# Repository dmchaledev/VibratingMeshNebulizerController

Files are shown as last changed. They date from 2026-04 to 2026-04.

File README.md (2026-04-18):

# Nimbus Nebulizer Controller

> **WARNING: THIS IS NOT AN FDA-APPROVED MEDICAL DEVICE.**
> This project is a research workaround for educational and investigational purposes only.
> It has not been evaluated, cleared, or approved by the FDA or any regulatory body.
> It is not intended to diagnose, treat, cure, or prevent any disease. Building and using
> this circuit is done entirely at your own risk. See [DISCLAIMER.md](DISCLAIMER.md) for
> full safety and legal information.

An open-source controller for vibrating mesh nebulizers, built on a breadboard for under $75. Based on [Microchip AN2265](https://static5.arrow.com/pdfs/2016/10/27/10/14/17/387/mcp_/manual/82300002265a.pdf) vibrating mesh nebulizer reference design.

## Why This Exists

The Aerogen Solo is a medical-grade vibrating mesh nebulizer used in ICUs and home ventilator circuits. The controller that drives it — the Aerogen Pro-X — costs **$2,700 out of pocket** and is not always covered by insurance. The nebulizer cup itself is ~$40 and has two simple electrical contacts: the leads of a piezoelectric ring. All the controller does is generate the right AC signal to make it vibrate.

This project provides everything you need to build a working controller on a breadboard using off-the-shelf parts from DigiKey, a $3 microcontroller, and free development tools from Microchip.

### v3.1 — Rechargeable + Display

v3.1 adds the three quality-of-life features that matter most for an
every-day nursery device: a rechargeable LiPo cell, USB-C charging,
and a status display.

- **Rechargeable 1S LiPo pouch cell** — ~2000 mAh (103450). Drops into
  an internal bay in the enclosure. Runs ~3-5 treatments per charge.
- **USB-C charging via TP4056 + DW01A** — plug in any USB-C cable to
  recharge. DW01A handles over-charge, over-discharge and short-circuit
  protection. The firmware adds a software cutoff at 3.1 V so it warns
  and stops cleanly before the hardware cutoff trips.
- **16x2 character OLED on the lid** — shows state, resonant
  frequency, elapsed treatment time, battery percent and voltage.
  Default is a character OLED (Winstar / Newhaven / Matrix Orbital,
  ~$25) which stays readable at any LiPo voltage (3.0–4.2 V). A
  cheap HD44780 LCD (~$3) also works; set `LCD_IS_OLED = 0`.
- **Split enclosure** — base and lid are now separate SCAD files
  sharing an `enclosure_config.scad`, so you can iterate on either
  without re-rendering the other.
- **Zero-parts battery monitor** — the PIC's built-in Fixed Voltage
  Reference doubles as a VDD meter, so battery voltage is read via
  ADC without any external divider.

### v3.0 — Turnkey Build

- **Single build path** — order a pre-assembled PCB from JLCPCB, plug in a boost module, flash firmware, done.
- **Continuous treatment mode** — runs until you press stop or the cup is empty.
- **Dry-cup auto-stop** — detects when the cup is empty and shuts down safely.
- **Frequency caching** — saves the resonant frequency to flash memory for fast startup.
- **Smart re-sweep** — when resonance drifts during a long session, does a fast 150ms targeted re-sweep.
- **3D-printable connector and enclosure** — parametric OpenSCAD designs.

## How It Works

The Aerogen Solo cup contains a PZT (Lead Zirconate Titanate) piezoelectric ring bonded to a perforated stainless steel mesh. When driven at its resonant frequency (~90-150 kHz) with ~30-60 Vpp, the mesh vibrates and pushes liquid through thousands of laser-drilled holes, creating a fine aerosol (MMAD ~3.4 um).

The controller:
1. **Boosts** battery/USB voltage up to ~10-20V
2. **Generates** a high-voltage AC waveform at 30-60 Vpp
3. **Sweeps** frequency from ~90-150 kHz to find the PZT's resonant peak
4. **Locks** onto that frequency and runs until medication is nebulized

## Vibrating Mesh Nebulizer Compatibility

This controller drives a PZT piezoelectric ring at its resonant frequency — the same fundamental mechanism used by all vibrating mesh nebulizers. The frequency sweep approach means it is **not hard-coded to a single device** and can, in principle, find the resonant frequency of any PZT-based mesh nebulizer cup.

| Brand | Product Line | Likely Compatible | Notes |
|---|---|:---:|---|
| **Aerogen** | Solo, Solo with Pro-X | Yes | Primary target of this project. ~128 kHz typical resonance. |
| **OMRON** | MicroAir (U22, U100) | Likely | Uses PZT mesh, similar frequency range. Different cup form factor — will need custom contact adapter. |
| **PARI Pharma** | eFlow / eFlow Rapid | Likely | PZT mesh design. Resonant frequency may differ — the sweep range in `config.h` may need widening. |
| **Philips Respironics** | InnoSpire Go | Possible | Vibrating mesh type. Limited public data on drive parameters. Test with caution. |
| **Drive DeVilbiss** | Aerogen-based devices | Yes | Several DeVilbiss ventilator-integrated nebulizers use Aerogen Solo cups internally. |

**Key caveats:**
- Each manufacturer's cup has a different mechanical form factor — you'll need to figure out how to make electrical contact with the two PZT leads for non-Aerogen cups
- Resonant frequencies vary by manufacturer and even unit-to-unit. The firmware sweeps 90-150 kHz by default; adjust `SWEEP_FREQ_MIN_HZ` and `SWEEP_FREQ_MAX_HZ` in `config.h` if your cup resonates outside that range
- Drive voltage requirements differ. **Always start with low voltage** and increase gradually
- This project has only been tested against Aerogen Solo cups. Compatibility with other brands is inferred from the shared operating principle, not from direct testing

## Repository Structure

```
├── README.md                 ← You are here
├── DISCLAIMER.md             ← Safety and legal notice (READ THIS FIRST)
├── docs/
│   ├── BUILD_GUIDE.md        ← Turnkey build guide and nursery durability tips
│   ├── DIAGRAMS.md           ← Visual diagrams (state machine, signal flow, etc.)
│   ├── JLCPCB_ORDERING_GUIDE.md ← How to order pre-assembled PCBs from JLCPCB
│   ├── BOM_TURNKEY.csv       ← Bill of materials — JLCPCB assembled build (~$15-25/board)
│   ├── SHOPPING_LIST.md      ← Where to buy every part, organised per supplier
│   └── IMPROVEMENTS.md       ← External review: suggested repo/design improvements
├── firmware/
│   ├── README.md             ← How to compile and flash
│   └── src/
│       ├── main.c            ← Main program and state machine
│       ├── config.h          ← Tunable parameters (frequencies, voltages, modes)
│       ├── peripherals.h     ← Peripheral function declarations
│       ├── peripherals.c     ← PIC16F1713 hardware initialization + HEF flash
│       ├── sweep.h           ← Frequency sweep declarations
│       └── sweep.c           ← Full sweep, narrow sweep, and frequency caching
└── hardware/
    ├── WIRING.md             ← Pin-by-pin wiring reference
    ├── adapters/             ← 3D-printable nebulizer cup connector
    │   ├── README.md         ← Measurement guide and assembly instructions
    │   ├── aerogen_connector_plug.scad ← Connector plug for Aerogen Solo cup pins
    │   └── universal_adapter.scad      ← Parametric adapter for other cup brands
    └── enclosure/            ← 3D-printable controller enclosure (v3.1 split)
        ├── enclosure_config.scad       ← Shared dimensions used by base and lid
        ├── controller_enclosure.scad   ← Base with LiPo + TP4056 bay
        └── controller_enclosure_lid.scad ← Lid with LCD/OLED window + standoffs
```

## Quick Start

1. **Read [DISCLAIMER.md](DISCLAIMER.md)** — understand what you're building
2. **Order the PCB** — follow [docs/JLCPCB_ORDERING_GUIDE.md](docs/JLCPCB_ORDERING_GUIDE.md), JLCPCB assembles the board for you
3. **Order parts** — copy the per-supplier cart from [docs/SHOPPING_LIST.md](docs/SHOPPING_LIST.md) (boost module, LiPo, TP4056, pogo pins, cables, screws). Full authoritative BOM in [docs/BOM_TURNKEY.csv](docs/BOM_TURNKEY.csv).
4. **3D print** the connector plug and enclosure from [hardware/](hardware/)
5. **Compile and flash** firmware per [firmware/README.md](firmware/README.md) (default config is ready to go)
6. **Assemble** — mount PCB in enclosure, plug in boost module and connector cable
7. **First power-up** following the procedure in [docs/BUILD_GUIDE.md](docs/BUILD_GUIDE.md)

## Key Reference Documents

| Resource | Description |
|---|---|
| [AN2265 Application Note (PDF)](https://static5.arrow.com/pdfs/2016/10/27/10/14/17/387/mcp_/manual/82300002265a.pdf) | Microchip's reference design this project is based on |
| [Microchip Demo Page](https://www.microchip.com/en-us/solutions/medical/demonstrations-and-design-files/vibrating-mesh-nebulizer) | Official source code download |
| [PIC16F1713 Datasheet](https://www.microchip.com/en-us/product/pic16f1713) | MCU datasheet |
| [Arrow Reference Design](https://www.arrow.com/en/reference-designs/vibrating-mesh-nebulizer-reference-design/f2a9476a8ee42cf52a40b74023c3b682227100c55cf2) | Arrow's page for the AN2265 design |
| [MDPI: Frequency & Voltage Effects](https://www.mdpi.com/2076-3417/11/3/1296) | Research on mesh nebulizer drive parameters |

## Estimated Cost (v3.1)

| Item | Cost |
|---|---|
| JLCPCB assembled PCB (5-board min) | ~$10-16/board |
| Boost module (MT3608) | ~$1-2 |
| 1S LiPo pouch cell (103450, 2000 mAh) | ~$8-12 |
| TP4056 + DW01A Type-C charger | ~$0.50-2 |
| 16x2 character OLED (Winstar WEH001602A, default) | ~$22-28 |
| 3D-printed connector + enclosure | ~$3-5 |
| Pogo pins + JST cables + screws | ~$3-5 |
| **Per-unit total (LCD)** | **~$30-45** |
| **Per-unit total (character OLED)** | **~$45-70** |
| Programmer (MPLAB Snap, one-time) | ~$35 |
| **First build total** | **~$75-105** |

JLCPCB minimum order is 5 boards, so you get spares. The programmer is a one-time purchase.

**Compare to:** Aerogen Pro-X controller — **$2,700** out of pocket.

## License

MIT — see [LICENSE](LICENSE).

*Based on Microchip AN2265 Rev B and publicly available research.*

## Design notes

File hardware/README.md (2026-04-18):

# Hardware

This directory holds everything needed to build the physical controller:
the wiring map, 3D-printable parts, and pointers to the schematic and
PCB sources.

## Contents

```text
hardware/
├── WIRING.md              ← Pin-by-pin reference for the breadboard build
├── adapters/              ← 3D-printable nebulizer cup connector
│   ├── README.md
│   ├── aerogen_connector_plug.scad
│   └── universal_adapter.scad
├── enclosure/             ← 3D-printable controller enclosure (split for v3.1)
│   ├── enclosure_config.scad     ← Shared dimensions for base + lid
│   ├── controller_enclosure.scad ← Base with LiPo + TP4056 bay
│   └── controller_enclosure_lid.scad
└── openscad/              ← Optional vendored OpenSCAD AppImage (Linux x86_64)
```

## Schematic and PCB Sources

The PCB this project ships against is the **Microchip AN2265 reference
design** with the modifications described in `docs/BUILD_GUIDE.md`. Two
ways to get the design files:

1. **Microchip / Arrow** — original reference design (PDF schematic,
   gerbers, BOM):
   - <https://www.microchip.com/en-us/solutions/medical/demonstrations-and-design-files/vibrating-mesh-nebulizer>
   - <https://www.arrow.com/en/reference-designs/vibrating-mesh-nebulizer-reference-design/f2a9476a8ee42cf52a40b74023c3b682227100c55cf2>
2. **JLCPCB-ready bundle** — see `docs/JLCPCB_ORDERING_GUIDE.md` for the
   pre-modified gerbers and a step-by-step ordering walkthrough.

Native KiCad sources (`.kicad_sch` / `.kicad_pcb`) for the v3.1 board
are **not yet** in this repo. Track <https://github.com/dmchaledev/VibratingMeshNebulizerController/issues>
for the open issue or open one if you'd like to help port the gerbers.

## Working with the OpenSCAD Models

Every printable part is a parametric `.scad` file. Two ways to render:

```bash
# GUI: open the file, F5 preview, F6 render, then File > Export > STL
openscad hardware/enclosure/controller_enclosure.scad

# Command line: produce an STL non-interactively
openscad -o /tmp/enclosure.stl hardware/enclosure/controller_enclosure.scad
```

Shared dimensions for the enclosure base and lid live in
`enclosure/enclosure_config.scad`. Edit those constants to retune both
parts at once instead of duplicating values.

CI renders every `.scad` in this directory on push (see
`.github/workflows/openscad.yml`). Files matching `*_config.scad` /
`*_common.scad` are treated as include-only and rendered indirectly by
their consumers — don't put a top-level `module` call in those files.

## About `openscad/OpenSCAD-2021.01-x86_64.AppImage`

A copy of the Linux OpenSCAD AppImage is vendored here for offline
builders. It is large (~40 MB) and not required if you've installed
OpenSCAD from your distribution's package manager or from
<https://openscad.org/downloads.html>.

> **Note:** vendoring binaries in Git inflates clone size for everyone.
> A future cleanup will move this into a release artifact instead. If
> you don't need the offline copy, install OpenSCAD via your package
> manager and ignore this directory.

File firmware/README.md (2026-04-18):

# Firmware — Build and Flash Instructions

## Prerequisites

### Software (all free)

1. **MPLAB X IDE** — download from https://www.microchip.com/en-us/tools-resources/develop/mplab-x-ide
2. **XC8 Compiler** — download from https://www.microchip.com/en-us/tools-resources/develop/mplab-xc-compilers
   - Install in Free mode (no license needed)
   - The free mode generates slightly less optimized code but works perfectly fine

### Hardware

- **MPLAB Snap** (~$35, DigiKey PG164100-ND) or **PICkit 4** (~$60) or **PICkit 5** (~$90)
- 5-wire connection from programmer to PIC16F1713 ICSP pins (see [hardware/WIRING.md](../hardware/WIRING.md))

## Quick Start (Make)

The repo ships with a Makefile that wraps the XC8 invocation:

```bash
cd firmware
make            # → firmware/build/nebulizer.hex
make program    # → flashes via MPLAB Snap (set PROGRAMMER=pickit4 etc.)
make clean
```

The Makefile auto-discovers every `.c` file in `src/`, so new sources
(such as `lcd.c` added in v3.1) are picked up without edits.

## Quick Start (Command Line)

If you'd rather call the compiler directly:

```bash
# Navigate to the firmware source directory
cd firmware/src

# Compile (adjust the XC8 path if needed). Pass every .c source.
xc8-cc -mcpu=16F1713 -O1 -o nebulizer.hex \
    main.c peripherals.c sweep.c lcd.c

# Program the chip (with MPLAB Snap connected via USB)
# Use MPLAB IPE (Integrated Programming Environment) or:
mdb.sh -e "device PIC16F1713; hwtool snap; program nebulizer.hex; quit"
```

## Using MPLAB X IDE

### Create a New Project

1. Open MPLAB X IDE
2. File > New Project
3. Select: Microchip Embedded > Standalone Project
4. Device: **PIC16F1713**
5. Tool: select your connected programmer (Snap, PICkit 4, etc.)
6. Compiler: **XC8 (latest version)**
7. Project name: `NebulizerController`
8. Finish

### Add Source Files

1. In the project tree, right-click "Source Files" > Add Existing Item
2. Add all `.c` files from this `src/` directory:
   - `main.c`
   - `peripherals.c`
   - `sweep.c`
   - `lcd.c`
3. Right-click "Header Files" > Add Existing Item
4. Add all `.h` files:
   - `config.h`
   - `peripherals.h`
   - `sweep.h`
   - `lcd.h`

### Compile

1. Click the **Build** button (hammer icon) or press F11
2. The output window should show `BUILD SUCCESSFUL`
3. If you get errors, verify:
   - XC8 compiler is selected (Project Properties > Compiler)
   - Device is set to PIC16F1713

### Program the Chip

1. Connect the programmer to the PIC16F1713 via the ICSP header
2. Connect the programmer to your computer via USB
3. Click **Make and Program Device** (green arrow with chip icon)
4. The output window should show programming succeeded

### Verify

After programming:
- The red LED should blink once at power-up (indicating the MCU is running)
- Press the button — the controller should begin sweeping (green LED will blink during sweep, then go solid when locked on resonance)

## Alternative: Download Microchip's Original AN2265 Source

If you'd rather use the original reference code:

1. Visit https://www.microchip.com/en-us/solutions/medical/demonstrations-and-design-files/vibrating-mesh-nebulizer
2. Download the source code ZIP
3. Open the included MPLAB X project directly
4. This is the exact code from the application note — it will compile for the SOIC package but works identically on the DIP version

## Source File Overview

| File | Purpose |
|---|---|
| `config.h` | All tunable parameters — frequencies, voltages, timing, firmware version. **Edit this first.** |
| `peripherals.h/c` | PIC16F1713 hardware initialization (oscillator, NCO, DAC, ADC, CWG, GPIO, UART) |
| `sweep.h/c` | Frequency sweep algorithm — scans for PZT resonance |
| `lcd.h/c` | Bit-bang I2C driver for the 16x2 character LCD/OLED on the lid |
| `main.c` | State machine: idle → sweep → run → stop. Button handling, treatment timer, LED control |

## Adjusting Parameters

All user-adjustable parameters are in `config.h`. The most important ones:

| Parameter | What It Does | Default |
|---|---|---|
| `SWEEP_FREQ_MIN_HZ` | Lower frequency bound | 90,000 Hz |
| `SWEEP_FREQ_MAX_HZ` | Upper frequency bound | 150,000 Hz |
| `SWEEP_STEP_HZ` | Frequency resolution | 500 Hz |
| `BOOST_TARGET_DAC` | Drive voltage level (**start low!**) | 16 |
| `TREATMENT_TIME_SEC` | Auto-shutoff timer | 600 (10 min) |

After changing `config.h`, rebuild and reprogram the chip.

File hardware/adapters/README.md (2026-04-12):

# Nebulizer Cup Connector System

3D-printable connector plug and adapters that provide reliable electrical contact between the controller and nebulizer cups.

**Read [DISCLAIMER.md](../../DISCLAIMER.md) before building.**

---

## Overview

The Aerogen Solo cup has a small rectangular connector housing (~1/2" x 1/2") on its bottom face containing two protruding pins (the PZT leads). The connector plug mates with this housing and connects via a flexible cable to the controller enclosure.

1. **A connector plug** that inserts into the cup's pin housing and makes spring-loaded contact
2. **A flexible cable** (30-50cm stranded wire) connecting the plug to the controller
3. **A JST-XH connector** for clean, repeatable connection at the controller end

---

## Available Designs

| File | Cup Model | Status |
|---|---|---|
| `aerogen_connector_plug.scad` | Aerogen Solo / Solo with Pro-X | Ready (approximate dimensions — update with calipers) |
| `universal_adapter.scad` | OMRON MicroAir, PARI eFlow, others | Parametric template (needs measurements) |

Both files are **parametric OpenSCAD** designs. Measure your cup, enter the dimensions, and export STL for printing.

---

## What You Need

### Hardware (per connector)

| Qty | Item | Source | Cost |
|-----|---|---|---|
| 2 | P75-B1 pogo pin sockets (receptacles) | Amazon/AliExpress "P75-B1 pogo pin" | ~$3/50-pack |
| 1 | JST-XH 2-pin connector + header pair | Amazon/DigiKey | ~$0.50 |
| 1 | Flexible stranded wire, 30-50cm (24-28 AWG, 2 conductors) | Any | ~$0 |
| 1 | 3D printed connector plug | Your printer or JLCPCB 3D printing | ~$1-3 |
| 1 | Small zip tie (for strain relief) | Any | ~$0 |

### Tools

- 3D printer (PETG or SLA resin) or order from JLCPCB/Shapeways
- Soldering iron (to solder wires to pogo pin sockets)
- Calipers (to verify cup connector dimensions)
- JST crimp tool or solder

---

## Measurement Guide — Aerogen Solo

The connector housing on the bottom of the Aerogen Solo cup looks like this:

```
    BOTTOM VIEW (looking up at the cup base)
    ==========================================

         +------------------+
         |                  |
         |    o        o    |   <-- two protruding pins
         |  (pin 1)  (pin 2)|
         |                  |
         +------------------+
              ~1/2" wide

    SIDE VIEW (cross-section through connector)
    ==========================================

         Cup body
        +---------+
        |         |
        | housing |       ^
        |  +---+  |       | housing_height
        |  | o |  |       |  (pin recess depth)
        |  +---+  |       v
        +----+----+
             |  pin protrusion
             v
```

### Critical Measurements (use calipers)

| Parameter | What to Measure | Estimated Value |
|---|---|---|
| `housing_width` | Width of the rectangular connector housing | ~12.7mm (1/2") |
| `housing_depth` | Depth of the rectangular connector housing | ~12.7mm (1/2") |
| `pin_spacing` | Center-to-center distance between the two pins | ~3.175mm (1/8") |
| `pin_diameter` | Diameter of each pin | ~1.0mm |
| `pin_length` | How far pins protrude from the housing floor | ~4.0mm |
| `housing_height` | Depth of the housing recess | ~6.0mm |

**The most critical measurement is `pin_spacing`.** If this is off by more than 0.2mm, the pogo sockets won't align with the pins. Measure this first and most carefully.

---

## Assembly

### Step 1: Print the Connector Plug

1. Open `aerogen_connector_plug.scad` in [OpenSCAD](https://openscad.org/) (free)
2. Update measurements with your caliper readings
3. Press F5 to preview, F6 to render
4. Export STL: File > Export > Export as STL
5. Print settings:
   - **Material:** SLA resin (best precision) or PETG
   - **Layer height:** 0.12-0.2mm (finer = better socket channel fit)
   - **Infill:** 50%+
   - **Supports:** Yes, for socket channels

### Step 2: Install Pogo Sockets

1. Insert a P75-B1 pogo socket (receptacle end up) into each channel from the bottom of the plug
2. The open bore of each socket should face the insertion face (toward the cup pins)
3. Optionally apply a tiny drop of CA glue to secure the socket barrel — avoid getting glue on the spring mechanism
4. Solder a 24-28 AWG stranded wire to each socket's solder cup

### Step 3: Route Cable

1. Route both wires through the cable channel to the cable exit
2. Thread the cable through the controller enclosure's cable gland **before** terminating
3. Crimp or solder wires to a JST-XH 2-pin plug
4. Secure cable with a zip tie in the strain relief slot

**Cable tips:**
- Use flexible silicone-insulated wire (survives repeated flexing)
- Keep cable 30-50cm (shorter = less noise pickup at 100+ kHz)
- Twist the two wires together to reduce EMI
- **No polarity requirement** — the PZT is an AC device

### Step 4: Test

1. Press the connector plug onto the Aerogen Solo cup's pins
2. You should feel slight resistance as the pins engage the pogo sockets
3. Measure continuity: < 1 ohm from each JST pin to the corresponding cup pin
4. Tug gently on the cable — the strain relief should hold

---

## Troubleshooting

| Problem | Cause | Fix |
|---|---|-----|
| Plug won't fit in housing | Plug too wide / deep | Increase `plug_clearance` by 0.1mm, reprint |
| Plug too loose in housing | Too much clearance | Decrease `plug_clearance` by 0.1mm |
| Pins don't align with sockets | `pin_spacing` measurement off | Re-measure with calipers, update, reprint |
| No continuity through socket | Solder joint broke or socket not seated | Re-solder wire, re-seat socket |
| Intermittent contact | Socket spring worn or medication residue | Clean with isopropyl alcohol, replace socket |
| Cable breaks at plug | Repeated flexing without strain relief | Secure cable with zip tie, use stranded wire |

---

## Design Notes

### Why Pogo Sockets (not clips or bare wire)?

The Aerogen Solo cup has a 28-day life, meaning regular cup changes. The connector plug needs to handle hundreds of connect/disconnect cycles reliably. Pogo pin sockets provide:

- **Self-centering** — spring mechanism guides the cup pin into alignment
- **Consistent contact force** — ~75g per pin regardless of insertion depth
- **100,000+ cycle rating** — effectively infinite for this application
- **Low contact resistance** — gold-plated tips, < 50 milliohm

### Why a Plug (not a Cradle)?

The previous adapter design used a cradle that the cup sat in. The plug design is better because:

- **Matches the actual connector** — the cup has pins in a housing, so we make a plug for that housing
- **Smaller and lighter** — just a small block on the end of a cable
- **More flexible positioning** — the cable lets you position the cup anywhere relative to the controller
- **Easier to print** — no large cradle to support during printing

### Cable Length

Keep the cable between 30-50cm. At the operating frequency of 100+ kHz:
- Longer cables act as antennas, picking up noise
- Cable capacitance can affect the output waveform
- The LC output circuit is tuned for a specific load — long cables add parasitic inductance

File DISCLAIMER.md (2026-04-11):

# Disclaimer and Safety Notice

## Read This Before You Build Anything

This project documents the construction of an electronic controller for a vibrating mesh nebulizer based on publicly available reference designs and datasheets. It is provided for **educational and informational purposes**.

## This Is Not a Medical Device

- This is **not** an FDA-cleared or CE-marked medical device
- It has **not** been tested or validated by any regulatory body
- It has **not** undergone electromagnetic compatibility (EMC) testing
- It has **not** been evaluated for electrical safety (IEC 60601)

## If You Build This

You are accepting personal responsibility for:

- **Verifying** the circuit operates correctly before connecting to a nebulizer cup
- **Testing** with normal saline first, never medication, until operation is stable and repeatable
- **Monitoring** the nebulizer cup temperature during operation — warmth indicates overdriving
- **Current-limiting** your power supply during development to prevent damage
- **Starting with low drive voltages** and increasing gradually — excess voltage can depolarize or crack the piezoelectric element
- **Keeping the circuit isolated** from any ventilator circuit during testing
- **Understanding** the electrical and clinical risks you are accepting

## Aerogen Solo Cup Lifespan

The Aerogen Solo cup has a manufacturer-specified 28-day intermittent-use life. This does not change with a DIY controller. Do not attempt to extend cup life beyond manufacturer specifications.

## Electrical Safety

- The boost converter in this circuit produces voltages up to 20V DC and the output stage generates 30-60 Vpp AC at ultrasonic frequencies
- While these voltages are not typically dangerous to adults, exercise standard electronics safety practices
- Never operate the circuit near water or conductive liquids other than what's in the nebulizer cup
- Keep the prototype away from children when powered

## Why This Exists

This project exists because the healthcare system sometimes fails people. When a child needs a $40 nebulizer cup driven by a simple AC signal, and the only legal way to get the controller costs $2,700 out of pocket, some parents have no choice but to learn the electronics themselves. This repository attempts to make that path as safe and informed as possible.

None of that changes the risks above. Be careful. Test thoroughly. When in doubt, ask for help.

## License

This project is released under the MIT License. The authors and contributors accept no liability for any damages arising from the use of this information. See [LICENSE](LICENSE).

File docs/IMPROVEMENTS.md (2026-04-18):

# Nimbus Nebulizer Controller — Improvement Suggestions

An external engineer's assessment of the repo at v3.1, with concrete
suggestions ordered by "bang for the buck." Written from the
perspective of someone looking at this project for the first time with
fresh eyes.

**Context.** This is a personal-use, educational build for a nursery
device driven 6+ times per day. It's not FDA-approved and is not
intended for distribution. That framing matters — some suggestions
below are worth it only if you want to make the design more accessible
to *other* builders; others are worth it just to make your own build
cheaper and faster.

**Scope.** This memo does not second-guess safety decisions already
made in the firmware. The soft LiPo cutoff, dry-cup auto-stop, and
max-DAC clamp are all clearly right. Suggestions are additive to those.

---

## TL;DR — Top 5 Concrete Wins

Ranked by impact ÷ effort. Each is expanded later in the doc.

| # | Suggestion | Effort | Payoff |
|---|---|---:|---|
| 1 | **Swap the $22–28 character OLED for a $3 SSD1306 0.96" OLED** | ~1 day firmware work | **Saves ~$20–25 per unit.** Single biggest line-item win. Adds graphical capability as a bonus. |
| 2 | **Publish pre-rendered STL + pre-built HEX as GitHub Release artifacts** | ~2 hr of CI glue | Removes the MPLAB X + OpenSCAD install barrier for anyone who doesn't need to modify. First-build wall-clock time drops ~1 hr. |
| 3 | **Evict root clutter: move PNG/PDF to `docs/images/` and `docs/references/`, rename `Nebulizer Reference Design/` (no space), drop the 39 MB vendored OpenSCAD AppImage** | ~1 hr | 40 MB lighter clone. Root directory becomes instantly scannable. Fixes the dir-name-with-space that your own `hardware/README.md` already flagged. |
| 4 | **Add an absolute-max treatment-time safety cap (e.g., 60 min) in CONTINUOUS mode** | ~20 LOC | Defense-in-depth. `CONTINUOUS + dry-cup-miss + silent sweep fail` is currently unbounded. |
| 5 | **Add `docs/GLOSSARY.md` + a single "Which build path is for me?" decision doc at root** | ~2 hr | First-time visitors currently hit PZT, NCO, CWG, HEF, FVR, MMAD, ICSP, HD44780, PCF8574, TP4056, DW01A, WS0010 within 10 pages. A one-pager demystifies all of them. |

Everything below is supporting detail and lower-priority items.

---

## 8. Prioritised Backlog

If I were picking up this repo Monday morning and had a week:

**Day 1 — free wins (no risk):**

- Move root PNGs → `docs/images/`, PDF → `docs/references/`, delete
  the vendored 39 MB OpenSCAD AppImage (publish as release asset
  instead), rename `Nebulizer Reference Design/` → `docs/references/
  an2265_reference/`. (§1.1)
- Add `docs/GLOSSARY.md` and `docs/CHOOSE_YOUR_PATH.md`. (§1.2, §1.3)
- Collapse cost tables into a single `docs/COSTS.md` linked from the
  rest. (§1.4)
- Add top-level `Makefile` with `firmware`, `stl`, `test`, `check`
  targets that delegate to the existing sub-Makefiles. (§1.7)

**Day 2 — release hygiene:**

- GitHub Actions workflow that publishes pre-rendered STLs and a
  default `.hex` on every tag. (§2.3)
- Surface `firmware/tests/` in README. (§1.6)

**Day 3 — safety adds:**

- `TREATMENT_HARD_MAX_SEC` cap (§5.1), `BOOST_VFDBK_MAX_ADC` trip
  (§5.2), resonance plausibility window (§5.3), power-on self-test
  (§5.4). All ~100 LOC of firmware, fully host-testable.

**Day 4–5 — BOM optimisation (requires PCB rev):**

- Swap character OLED for SSD1306 0.96" (§2.1).
- Standardise on JST-XH + M3 (§2.2).
- Panelise the PCB for 10-up on JLCPCB.

**Day 6 — architecture rethink (optional):**

- USB-C PD trigger path in parallel with the MT3608 (§2.5).

**Beyond:** RP2040 port, logging, kit fulfilment — all §7 items are
separate projects in their own right.

## 9. Cross-References

- `docs/SHOPPING_LIST.md` — concrete per-supplier cart list for every
  part in the current v3.1 BOM, organised to minimise shipping trips.
- `docs/BOM_TURNKEY.csv` — authoritative BOM; SHOPPING_LIST is the
  "how to buy it" layer on top.
- `CHANGELOG.md` — history of what was tried and why. Read this
  before proposing anything that sounds like a revert.

---

*This memo was written as an external review and reflects one
reader's judgement. The maintainer's priorities and safety decisions
take precedence.*

### 6.1  Things that are notably well done — don't regress

Worth calling out explicitly so future contributors know what *not* to
"simplify away":

- **Stubbed-transclusion test pattern** in `firmware/tests/`
  (`#define` around hardware blocks, then `#include` the `.c`). Lets
  the host compiler run the same source that ships. Clean solution to
  the "`xc.h` isn't a host header" problem.
- **`LCD_IS_OLED` single driver for three different 1602 modules.**
  One codepath, three displays, $3–$28 price range. Nice.
- **FVR-as-ADC-reference battery meter** — zero external parts for
  battery voltage read. Elegant.
- **HEF frequency caching** with narrow re-sweep fallback —
  measurable UX improvement (150 ms vs 2.4 s cold start).

### 6.2  Config drift between docs and code

`config.h`'s pin comments and `hardware/WIRING.md`'s pin table are
duplicates that can drift. Two options:

- Generate `WIRING.md` from `config.h` with a short Python script in CI
- Or just add a comment at the top of each: "source of truth:
  `config.h`" vs "source of truth: `WIRING.md`", and link reciprocally

I'd go with the second — lighter touch.

### 6.3  Bit-bang I²C vs hardware MSSP

`lcd.c` bit-bangs I²C on RC4/RC5. The PIC16F1713 has an MSSP module
that could run hardware I²C at 100 or 400 kHz with less CPU overhead.
Given that the LCD refresh is only 2 Hz, this is **not** worth
touching — the bit-bang is simpler and works. Flag for future
contributors: don't "optimise" this unless you're freeing CPU for
something else.

### 6.4  UART debug default

`UART_ENABLED = 1` by default is good for debugging; consider flipping
to 0 for tagged releases to save a handful of bytes of flash and
reduce the chance of someone confused by UART traffic they didn't
intend to see. `BUILD_GUIDE.md` already documents enabling it when
needed.

## 7. Bigger Bets — Worth Considering, Not Recommending

Each of these is a larger architectural shift. They're listed for
completeness, not as near-term proposals.

### 7.1  Port firmware to Raspberry Pi Pico (RP2040)

- **Pros.** $4 board with native USB mass-storage bootloader — no
  $35 programmer ever again. Free GCC toolchain. More RAM/flash.
  Easier for hobbyist contributors to get into.
- **Cons.** Complete firmware rewrite. Abandons the AN2265 lineage
  that underpins the project's credibility. PIO makes frequency
  generation straightforward but PIO assembly is a new thing to
  learn. The RP2040 family is younger and has a fresher supply chain
  risk profile.
- **Verdict.** Interesting as a **parallel** target, not a
  replacement. A `firmware-rp2040/` alongside `firmware/` would let
  contributors pick.

### 7.2  Arduino Nano "breadboard try-before-you-buy" target

A stripped-down firmware that runs on an Arduino Nano with a single
MOSFET and a boost module, producing mist on a benchtop without any
PCB fabrication. Aimed at people who want to validate the concept in
an evening before committing to JLCPCB. Fires the NCO via AVR
Timer1/OC1A at ~100 kHz.

- **Pros.** On-ramp for hobbyists.
- **Cons.** Divergent codepath, more maintenance. Probably not worth
  it unless the project wants to broaden its audience.

### 7.3  WiFi-connected variant (ESP32-C3) for treatment logging

Log every treatment (start time, resonance frequency found, elapsed
duration, battery at start, dry-cup trigger vs manual stop) to a
local MQTT broker or a file on SD. For a chronic-care nursery use
case, that's a real clinical-value add.

- **Pros.** Observability. Lets a parent or care team notice "cup is
  getting less efficient" before the mesh fully fails.
- **Cons.** Wildly out of scope for v3.1. Security becomes a concern.
  Probably a v5 discussion.

### 7.4  Sell pre-assembled kits

Nothing about this project would be hard to fulfill at ~$60/unit as
a kit including a flashed PCB, printed parts, and all cables. There's
demand — Aerogen Pro-X at $2,700 has priced out most home users. But
taking money for a medical-adjacent device opens FDA/CE/liability
questions that aren't worth touching as an individual maintainer.
Note it exists, don't pursue it.

 — Concrete Per-Unit Savings

Starting from v3.1's ~$60 midpoint BOM with character OLED:

| Change | Before | After | Saving |
|---|---:|---:|---:|
| SSD1306 OLED (§2.1) | $25 | $3 | **−$22** |
| All-JST-XH + all-M3 kits (§2.2) | $8 | $3 | **−$5** |
| Panelize 5 boards → 10 in one JLCPCB order | $14/board | $11/board | **−$3/board** |
| USB-C PD trigger in place of MT3608 (§2.5) | $2 | $2 | $0 direct, but removes the mis-calibration failure mode |
| Drop the vendored AppImage | — | — | No $ saving, but 40 MB clone saving |
| **Net per-unit savings if you do §2.1 + §2.2 + panelize** | | | **~$30 / unit** |

Put differently: the **same budget** that bought 5 v3.1 units now
buys 10.

## 4. Speed-to-Build — Friction Inventory

Actual wall-clock time for a first-time builder, broken down:

| Step | Today | With the proposals |
|---|---:|---:|
| MPLAB X + XC8 install | ~45 min | 0 (use pre-built `.hex`, §2.3) |
| OpenSCAD install + render | ~20 min | 0 (use pre-rendered STL, §2.3) |
| MT3608 trim-pot calibration | ~10 min + a multimeter | 0 (USB-C PD trigger, §2.5) |
| JLCPCB lead time | 4–10 business days | unchanged |
| 3D print base + lid + plug | 3 × separate queues | 1 plate print (§2.7) |
| PIC flash via Snap | ~2 min | unchanged |
| Enclosure assembly | ~30 min | unchanged |

**Before:** roughly 2 hours active work + 1 week lead time for a
first build, assuming nothing goes wrong.

**After §2.3 alone:** 1 hour active work + 1 week lead time. The
"download MPLAB" yak is gone for casual builders.

## 5. Safety-Robustness Additions

These are additive to existing safety features, not replacements.

### 5.1  Absolute-max treatment-time cap regardless of mode

`TREATMENT_MODE_CONTINUOUS` runs until button-press, dry-cup
detection, or battery cutoff. That's correct **when those detections
fire.** In the (low-probability) case where the cup is wet but low-
fill and the dry-cup detection is marginal, the treatment could run
indefinitely.

Add an absolute ceiling:

```c
/* firmware/src/config.h — new */
#define TREATMENT_HARD_MAX_SEC   3600   /* 60 min absolute cap, any mode */
```

In `main.c`, the treatment-time tick comparison already exists in
TIMED mode — just also run it in CONTINUOUS with `TREATMENT_HARD_MAX_SEC`.
Fewer than 20 LOC and meaningful defense-in-depth.

### 5.2  VBOOST overvoltage trip (MODULE mode)

If the MT3608 trim-pot drifts or is bumped, the boost output can
swing up to ~28 V. The PZT can be damaged or depolarised at those
levels. You already read VBOOST via `ADC_CH_BOOST_VFDBK` for the
"Vboost too low" diagnostic — also trip on "Vboost too high."

```c
/* in sweep.c / main.c VBOOST check path */
if (boost_v_adc > BOOST_VFDBK_MAX_ADC) {
    lcd_show_error("VBOOST HIGH", "Check trim pot");
    state = STATE_ERROR;
    /* Don't start sweep; PZT protection */
}
```

Pick `BOOST_VFDBK_MAX_ADC` at ~15 V scaled through R5/R8 — leaves
margin above nominal 12 V but trips cleanly below any level
concerning for the PZT.

### 5.3  Resonance-implausibility guard

The firmware currently accepts any peak above `RESONANCE_THRESHOLD`
anywhere in the sweep range. If EMI or ADC noise produces a false
peak at, say, 91 kHz for an Aerogen Solo cup (which resonates ~128
kHz), the controller happily "locks" and drives the PZT off-resonance,
heating the mesh without producing mist.

Add a plausibility window: reject peaks that fall outside
`[PLAUSIBLE_MIN_HZ, PLAUSIBLE_MAX_HZ]` (per-brand) or outside ±10 kHz
of the cached frequency if one exists. Prompts a full re-sweep
instead of a bad lock.

### 5.4  Power-on self-test

On boot, before the first button press:

1. Measure VDD (you already do this)
2. Measure VBOOST (already supports this)
3. Drive NCO at a low-duty known frequency for 10 ms with no cup and
   confirm current-sense stays below an idle threshold

If any check fails, splash screen shows `SELFTEST FAIL` with a code
rather than silently proceeding. ~40 LOC.

Each idea here has a **trade-off** named explicitly. None are free.

### 2.1  Replace character OLED with SSD1306 0.96" I²C OLED  *(recommended)*

**Current.** Winstar WEH001602A or Newhaven NHD-0216AW character
OLED + PCF8574 backpack: ~$22–28 per unit.

**Proposed.** Generic SSD1306 0.96" 128×64 monochrome OLED, I²C
0x3C: ~$3 per unit.

| Dimension | Character OLED | SSD1306 |
|---|---|---|
| Unit cost | $22–28 | ~$3 |
| Voltage range | 3.0–5.5 V | 3.3–5 V (works down to ~3.0 V on most modules) |
| Readable in dark | ✔ | ✔ (self-emissive) |
| I²C, same PCB header | ✔ | ✔ |
| Info density | 32 chars, 2 lines | Full graphics — frequency dial, SOC bar, waveform |
| Firmware cost | Existing ~280 LOC in `lcd.c` | +200 LOC for a minimal font + primitives, *or* reuse a public SSD1306 driver |
| LCD-fallback path | HD44780 option exists | Would be a separate `#if LCD_IS_OLED == 2` branch |

**Trade-off.** More firmware code (rendering, font table). Worth it:
saves > $20 every build and opens the door to a live frequency graph /
battery curve on the lid.

**Safety note.** SSD1306 draws more current than a character LCD (full
screen ~20 mA). That's still < 1 % of a treatment-cycle budget, so
battery runtime is unaffected.

### 2.2  Standardise connector families: all JST-XH, all M3

**Current.** The BOM mixes JST-XH (cup, boost) with JST-PH (battery),
and M2.5 (PCB mount) with M3 (LCD mount). Two cable kits, two screw
kits, two crimp pin types.

**Proposed.**

- All JST-XH, everywhere. The battery header becomes JST-XH 2-pin with
  the same 2.5 mm pitch as the others. JST-XH is rated to 3 A vs
  JST-PH's 2 A — better margin for the 500 mA peak cup draw anyway.
- All M3 screws. Widen the PCB mount holes from 2.7 mm (M2.5 clearance)
  to 3.2 mm (M3 clearance). One screw pack, one driver tip.

**Savings.** ~$5 per first build (one fewer kit), and the end-of-build
"I have the wrong screw in my hand" moment goes away.

**Trade-off.** JST-PH is slightly smaller — if your enclosure is
already tight at the battery bay, verify the JST-XH header fits in the
x-y footprint. It should: JST-XH is ~7.5 × 5.5 mm vs JST-PH's
~5.0 × 4.0 mm per 2-pin module.

### 2.3  Pre-rendered STL + pre-built `.hex` as GitHub Release artifacts

**Current.** Every builder must:

- Install OpenSCAD (~100 MB) to render three STLs
- Install MPLAB X (~1.5 GB) + XC8 (~500 MB) to produce one `.hex`

The firmware is entirely driven by `config.h` defaults for the
turnkey build — most builders never edit a line of C.

**Proposed.** On every tagged release, CI produces:

- `nimbus_enclosure_base.stl`, `nimbus_enclosure_lid.stl`,
  `aerogen_connector_plug.stl` rendered from the committed SCAD
- `nimbus_default_v3.1.hex` built with default `config.h`
- Bundled as a GitHub Release under `v3.1`

**Savings.** Removes a 2 GB install for non-modifying builders. First-
build wall-clock time drops by ~1 hour.

**Trade-off.** Anyone wanting a non-default `SWEEP_FREQ_MAX_HZ`,
`TREATMENT_MODE`, or `LCD_IS_OLED` still needs the toolchain — that's
fine. Document "default build is in Releases, build from source if you
need to change `config.h`."

### 2.4  Containerise the firmware build  *(alternative to 2.3 for source modifiers)*

**Current.** A builder who *does* want to change `config.h` goes
through a ~45 minute Microchip account + MPLAB X + XC8 installation.

**Proposed.** A `Dockerfile` at `firmware/Dockerfile` that installs
XC8 inside a container. Then:

```bash
docker build -t nimbus-fw firmware/
docker run --rm -v $PWD/firmware:/src nimbus-fw make
```

Microchip's XC8 installer is Linux-capable and works fine headless.
The PIC Snap still has to run on the host (USB passthrough), but
compilation is the 45-minute step, not flashing.

**Trade-off.** XC8's license terms for redistribution must be read
carefully before publishing the Dockerfile. Distributing the installer
is typically forbidden; distributing a Dockerfile that *downloads* it
at build time is typically fine.

### 2.5  Eliminate the boost converter with a USB-C PD trigger  *(bigger bet)*

**Current.** USB → LiPo → MT3608 boost module @ manually-tuned 12 V →
output stage. The MT3608 trim-pot adjustment is the single
most-common first-build error (set the trim wrong, get no mist and
scratch your head).

**Proposed.** In wall-powered mode, drive the output stage directly
from a USB-C PD trigger module (CH224K, IP2721, etc.). Any modern
20 W+ USB-C PD wall brick negotiates 12 V ± 5 % — better than a
hand-tuned trim-pot. Module is ~$2.

Keep the LiPo + TP4056 path for portable operation, but add a diode-
OR so USB-C-PD power takes priority when plugged in:

```
   USB-C PD ──── 12 V ────┬─── Output stage
                          │
   LiPo ── MT3608 ── 12 V ┘
```

**Savings.** Removes one manual calibration step. Moves the nursery
use case (device plugged in overnight) to a factory-tight 12 V supply.

**Trade-off.** Architectural change. Needs PCB rev. Worth doing at
the same time as the SSD1306 swap if you're going to respin the board
anyway.

### 2.6  Collapse the TP4056 + DW01A + MT3608 chain into a single IP5306  *(bigger bet)*

**Current.** Three modules in the battery path: charging IC + protection
IC + boost IC. All cheap but all discrete.

**Proposed.** IP5306 (the chip inside every $5 USB power bank) does
charge + over/under-voltage protection + step-up to 5 V in one
package. Pair with a second small boost from 5 V to 12 V *or* drive
the output stage at 5 V with a different LC tuning.

**Trade-off.** This is a clean-sheet rewrite of the power path. It
collapses three modules to one and makes the BOM stupider-simple, but
it abandons the AN2265 reference inheritance on the charger side.
Only worth it if you're already rev'ing the PCB.

### 2.7  Ship one print file that stages base + lid + plug on one plate

**Current.** Three separate SCAD → STL files. Three separate
print-job setups.

**Proposed.** Add `hardware/enclosure/plate.scad` that imports all
three parts oriented flat and spaced for a single 220 × 220 mm print
bed. One click, one print.

**Trade-off.** Someone with a smaller bed (e.g., Prusa Mini at
180 × 180 mm) still needs the individual files — keep them.

### 1.1  Root-directory cleanup

The repo root currently holds 2.6 MB of mixed binary assets alongside
governance docs:

```
connector_plug.png               65 KB   ← move to docs/images/
nimbus_enclosure.png            108 KB   ← move to docs/images/
nimbus_enclosure_lid.png        113 KB   ← move to docs/images/
vibrating_mesh_nebulizer_design.pdf   2.3 MB  ← move to docs/references/
Nebulizer Reference Design/     9.6 MB  ← rename (drop space), move to references/
hardware/openscad/…AppImage     39 MB   ← delete, publish as release asset
```

Why it matters: a first-time visitor landing on GitHub sees 12+ top-
level items of very uneven importance. The AppImage alone makes clones
40 MB heavier than they need to be — `hardware/README.md` already
flags this; just do it.

Proposed layout:

```
/
├── README.md
├── DISCLAIMER.md   SECURITY.md   CONTRIBUTING.md   LICENSE   CHANGELOG.md
├── docs/
│   ├── images/               (PNGs currently at root)
│   ├── references/           (AN2265 PDF + the vendored reference bundle)
│   ├── BUILD_GUIDE.md  JLCPCB_ORDERING_GUIDE.md  DIAGRAMS.md
│   ├── BOM_TURNKEY.csv  SHOPPING_LIST.md  IMPROVEMENTS.md
│   ├── GLOSSARY.md           (new — see §1.3)
│   └── CHOOSE_YOUR_PATH.md   (new — see §1.4)
├── firmware/
└── hardware/
```

### 1.2  "Choose your path" decision doc

The README's Quick Start assumes JLCPCB turnkey. That's the right
default — but someone arriving with an existing breadboard or with no
3D printer wants a decision aid, not a guess-and-backtrack through
seven docs.

A short decision matrix at root or in `docs/CHOOSE_YOUR_PATH.md`:

| Starting point | Recommended path | Time to first mist |
|---|---|---:|
| Nothing but a laptop | JLCPCB turnkey + home-print *or* JLCPCB 3D print service | ~1 week (lead time) |
| Own 3D printer, no soldering | JLCPCB turnkey (PCB only), home-print adapter/enclosure | ~1 week |
| Soldering iron + protoboard skills | Hand-solder the AN2265 SOIC-28 board | ~1 weekend |
| "Just want to see it work" | Breadboard + DIP PIC16F1713 from DigiKey | ~1 evening |

### 1.3  Add `docs/GLOSSARY.md`

Every acronym used across the docs defined in one place. At minimum:
PZT, VMN, MMAD, NCO, CWG, HEF, FVR, SOC, ICSP, MPLAB, XC8, HD44780,
WS0010, US2066, PCF8574, JST-XH, JST-PH, TP4056, DW01A, MT3608, DAC,
ADC, DIP/SOIC, FR-4, HASL, SMT/SMD.

### 1.4  Single source of truth for cost numbers

Cost tables appear in README.md, BUILD_GUIDE.md, BOM_TURNKEY.csv, and
JLCPCB_ORDERING_GUIDE.md — I counted four slightly-different versions.
Pick one canonical table (the CSV or a new `docs/COSTS.md`), and have
the others link to it. This drifts every time prices change.

### 1.5  Images referenced from the README

The three PNGs currently at root are not visibly embedded in any
markdown doc I can see. If they're rendered OpenSCAD previews, embed
them in `README.md` under a "Gallery" section so they justify their
presence. Otherwise delete.

### 1.6  Surface the test harness

`firmware/tests/` is excellent but almost invisible from the README.
A one-line "This project has host-side unit tests — see
`firmware/tests/README.md`" near the Repository Structure section
flags the quality bar for new contributors.

### 1.7  Consider a top-level `Makefile` or `justfile`

Common flows — `build-firmware`, `build-stls`, `test`, `lint`, `clean`
— are currently spread across `firmware/Makefile`,
`firmware/tests/Makefile`, shell invocations of `openscad`, and
`pre-commit run`. A single top-level entrypoint (`make firmware`,
`make stl`, `make test`, `make check`) is the single strongest onboarding
signal in an open repo.

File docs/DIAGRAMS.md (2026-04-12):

# Controller Design Diagrams

Visual guides to how the vibrating mesh nebulizer controller works. These diagrams render automatically on GitHub.

---

## Controller State Machine

How the controller moves between states from power-on to nebulization:

```mermaid
stateDiagram-v2
    [*] --> IDLE : Power on

    IDLE --> SWEEP : Button press

    SWEEP --> RUNNING : Resonance found
    SWEEP --> ERROR : No resonance\n(no cup?)

    RUNNING --> IDLE : Button press (manual stop)
    RUNNING --> IDLE : Dry cup detected\n(auto-stop)
    RUNNING --> IDLE : Timer expired\n(timed mode only)
    RUNNING --> SWEEP : Narrow re-sweep failed\n(full re-sweep needed)

    ERROR --> IDLE : Button press (retry)

    note right of IDLE : Red LED solid
    note right of SWEEP : Green LED blinking
    note right of RUNNING : Green LED solid
    note right of ERROR : Red LED blinking
```

---

## Circuit Block Diagram

How power and signals flow through the controller:

```mermaid
flowchart LR
    subgraph POWER ["Power Supply"]
        BAT["Battery / USB\n4.5-5V"] --> FUSE["1A Fuse"]
        FUSE --> BOOST["Boost Converter\n(discrete or module)"]
        BOOST --> VBOOST["VBOOST\n10-20V DC"]
    end

    subgraph MCU ["PIC16F1713"]
        NCO["NCO\n90-150 kHz"] 
        ADC["ADC\n10-bit"]
        LOGIC["State Machine\n+ Sweep Algorithm"]
    end

    subgraph OUTPUT ["Output Stage"]
        Q4["Q4 MOSFET\n(IRLML0100)"]
        LC["LC Circuit\nL2+L3+C7"]
        PZT["PZT Cup\n(Aerogen Solo)"]
    end

    subgraph SENSE ["Feedback"]
        ISENSE["Current\nSense R18"]
        VPEAK["Peak Voltage\nDetector"]
    end

    NCO -->|Square wave| Q4
    VBOOST --> Q4
    Q4 --> LC
    LC --> PZT
    PZT --> ISENSE
    LC --> VPEAK
    ISENSE -->|AN1| ADC
    VPEAK -->|AN2| ADC
    ADC --> LOGIC
    LOGIC --> NCO
```

---

## Frequency Sweep Algorithm

How the controller finds the PZT's resonant frequency:

```mermaid
flowchart TD
    START(["Button Pressed"]) --> CACHE{"Cached frequency\nin flash?"}

    CACHE -->|"Yes"| NARROW["Narrow sweep\n+/- 3 kHz around cache\n~150 ms"]
    CACHE -->|"No"| FULL["Full sweep\n90-150 kHz in 500 Hz steps\n~2.4 sec"]

    NARROW -->|"Peak above\nthreshold"| FOUND["Resonance Found"]
    NARROW -->|"No peak"| FULL

    FULL -->|"Peak above\nthreshold"| FOUND
    FULL -->|"No peak"| NOCUP["ERROR:\nNo cup detected"]

    FOUND --> SAVE["Save frequency\nto flash cache"]
    SAVE --> LOCK["Lock NCO onto\npeak frequency"]
    LOCK --> RUN(["Start Nebulizing"])

    NOCUP --> BLINK(["Blink red LED\nWait for retry"])

    style FOUND fill:#2d6,color:#fff
    style NOCUP fill:#d33,color:#fff
    style RUN fill:#2d6,color:#fff
```

---

## Treatment Session Flow

What happens during a complete nebulization session:

```mermaid
flowchart TD
    IDLE(["IDLE\nRed LED solid"]) -->|"Button\npress"| SWEEP["Frequency Sweep\n(~150 ms cached,\n~2.4 sec full)"]
    SWEEP -->|"Found"| NEB["Nebulizing\nGreen LED solid"]

    NEB --> TICK{"Every\n5 seconds"}
    TICK -->|"Current OK"| NEB
    TICK -->|"Current\ndropped"| DRIFT{"Below dry-cup\nthreshold?"}

    DRIFT -->|"No, just drift"| RESWEEP["Narrow Re-sweep\n~150 ms"]
    DRIFT -->|"Yes, sustained\n3 seconds"| DRY(["DRY CUP\nAuto-stop"])

    RESWEEP -->|"Re-locked"| NEB
    RESWEEP -->|"Failed"| FULLSWEEP["Full Re-sweep\n~2.4 sec"]
    FULLSWEEP -->|"Found"| NEB
    FULLSWEEP -->|"Failed"| ERR(["ERROR\nCup removed?"])

    NEB -->|"Button press"| STOP(["MANUAL STOP"])
    NEB -->|"Timer expired\n(timed mode)"| DONE(["TREATMENT\nCOMPLETE"])

    style DRY fill:#f90,color:#fff
    style STOP fill:#69c,color:#fff
    style DONE fill:#2d6,color:#fff
    style ERR fill:#d33,color:#fff
```

---

## Resonance Detection Concept

Why the frequency sweep works — the PZT draws maximum current at its resonant frequency:

```mermaid
flowchart LR
    subgraph BELOW ["Below Resonance"]
        B1["Drive at 100 kHz"] --> B2["Low current\n(high impedance)"]
        B2 --> B3["Weak vibration\nNo mist"]
    end

    subgraph AT ["At Resonance (~128 kHz)"]
        A1["Drive at 128 kHz"] --> A2["Peak current\n(min impedance)"]
        A2 --> A3["Strong vibration\nFine mist!"]
    end

    subgraph ABOVE ["Above Resonance"]
        C1["Drive at 145 kHz"] --> C2["Low current\n(high impedance)"]
        C2 --> C3["Weak vibration\nNo mist"]
    end

    style AT fill:#e8f5e9,stroke:#2d6
    style A3 fill:#2d6,color:#fff
```

---

## Power Path

How the boost module provides high-voltage DC to the output stage:

```mermaid
flowchart LR
    INPUT["USB 5V\nor\n3x AAA 4.5V"] --> FUSE["1A\nFuse"]
    FUSE --> MODULE["MT3608/XL6009\nBoost Module"]
    MODULE --> VBOOST["VBOOST\n~12V DC"]
    VBOOST --> OUTPUT["Output Stage\n(LC Circuit + PZT)"]
    TRIM["Trim pot\n(set once)"] -.->|"Voltage\nadjust"| MODULE

    style MODULE fill:#e8f5e9
```

---

## ADC Feedback Signals

What the MCU measures during operation:

```mermaid
flowchart TD
    subgraph SIGNALS ["ADC Channels"]
        AN1["AN1 (pin 3)\nOutput Current"]
        AN2["AN2 (pin 4)\nPeak Voltage"]
    end

    subgraph USAGE ["What They Tell Us"]
        U1["PRIMARY: Resonance\ndetection + dry cup"]
        U2["Output waveform\namplitude"]
    end

    AN1 --> U1
    AN2 --> U2

    style AN1 fill:#2d6,color:#fff
    style U1 fill:#2d6,color:#fff
```

**AN1 (output current) is the most important signal.** It's how the controller finds resonance, tracks resonance drift, and detects a dry cup. The sweep algorithm measures this at each frequency step — the frequency with the highest AN1 reading is the resonant frequency. (AN0 and AN3 are used only in discrete boost mode and are unused in the turnkey build.)

---

## Mechanical: What Happens Inside the Cup

```mermaid
flowchart TD
    A["PZT Ring\n(piezoelectric ceramic)"] -->|"Driven at\nresonant freq\n~128 kHz"| B["Ring vibrates\nin flexural mode"]
    B --> C["Perforated mesh\n(bonded to ring)\nvibrates up/down"]
    C --> D["Liquid forced through\n~3000 laser-drilled holes\n(~4 um diameter)"]
    D --> E["Fine aerosol\nMMAD ~3.4 um\n(reaches deep lung)"]

    F["Medication loaded\ninto cup reservoir"] --> D

    style E fill:#2d6,color:#fff
```

The two exposed contacts on the Aerogen Solo cup connect directly to the PZT ring. There's no polarity — it's an AC device. The controller's job is simply to generate the right frequency and voltage to make the ring vibrate optimally.

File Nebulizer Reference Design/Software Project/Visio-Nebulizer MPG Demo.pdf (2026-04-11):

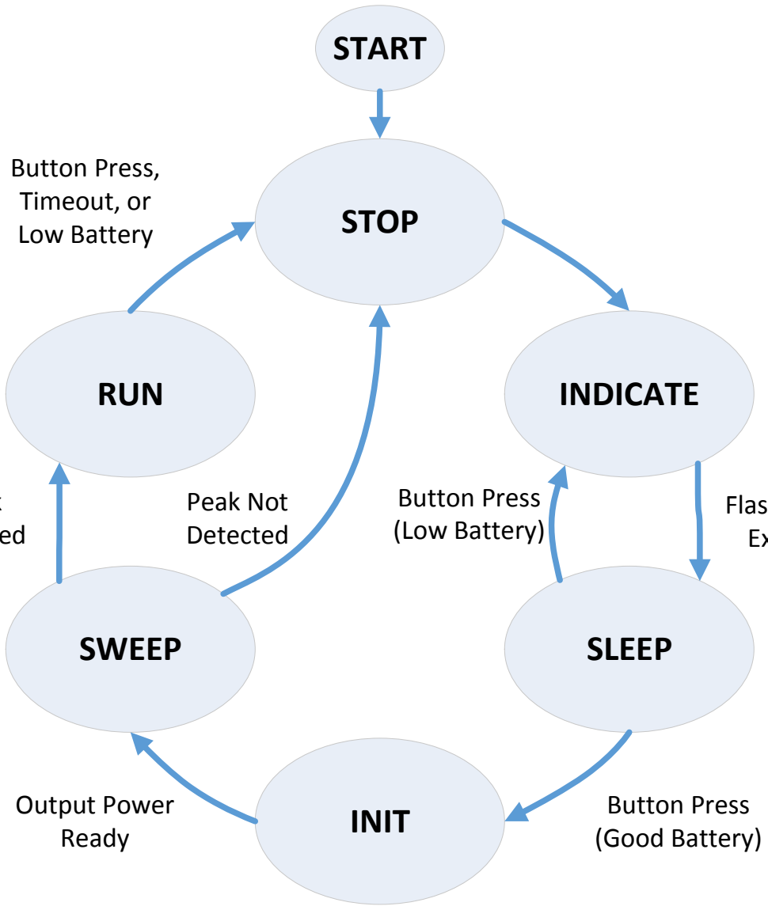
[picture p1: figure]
STOP; INIT; INDICATE; SLEEP; RUN; SWEEP; START; Button Press (Low Battery); Button Press (Good Battery); Output Power Ready; Peak Not Detected; Button Press, Timeout, or Low Battery

# Flash Timer Expired

# Peak Detected

# State Machine

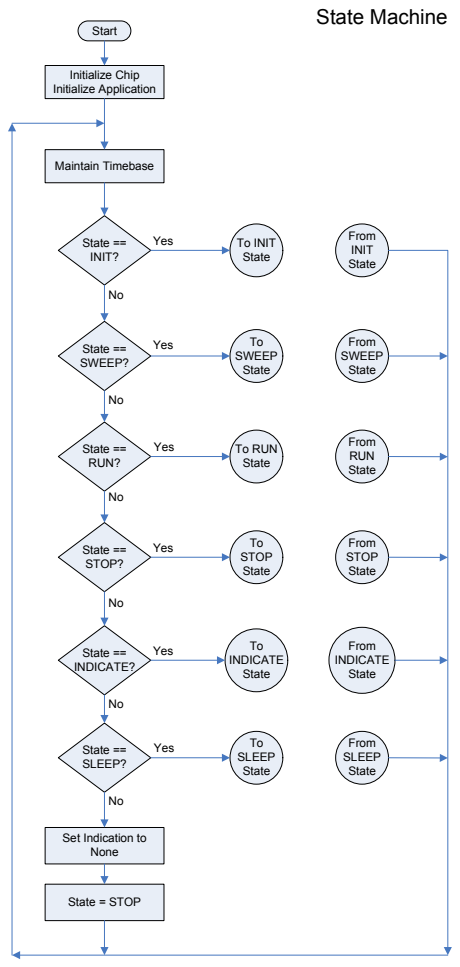
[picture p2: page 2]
Start; Initialize Chip Initialize Application; State == SWEEP?; Yes; State == RUN?; State == STOP?; State == SLEEP?; State == INIT?; To INIT State; From INIT State; To SWEEP State; From SWEEP State; To RUN State; From RUN State; State == INDICATE?; To STOP State; From STOP State; To INDICATE State; From INDICATE State; To SLEEP State; From SLEEP State; Maintain Timebase; State = STOP

Set Indication to
None

# Init State

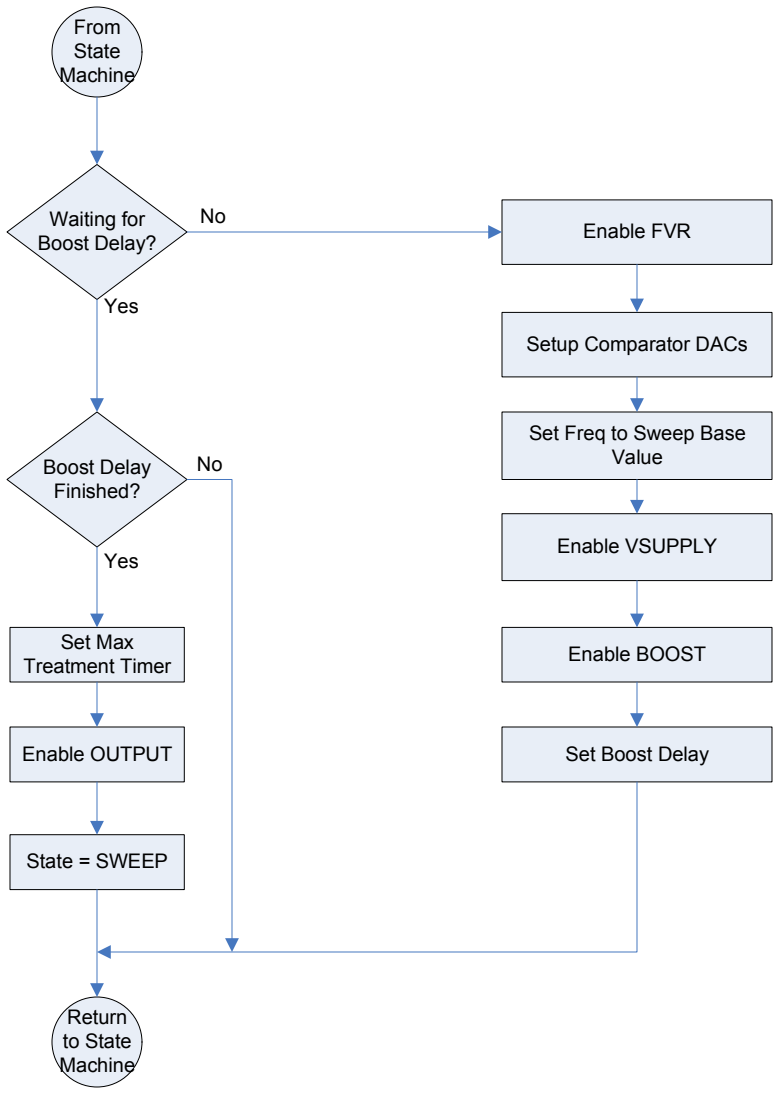
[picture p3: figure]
Enable FVR; Set Freq to Sweep Base Value; Enable BOOST; State = SWEEP; From State Machine; Return to State Machine; Enable VSUPPLY; Setup Comparator DACs; Waiting for Boost Delay?; Boost Delay Finished?; Enable OUTPUT; Set Boost Delay; Yes; Set Max Treatment Timer

# Sweep State

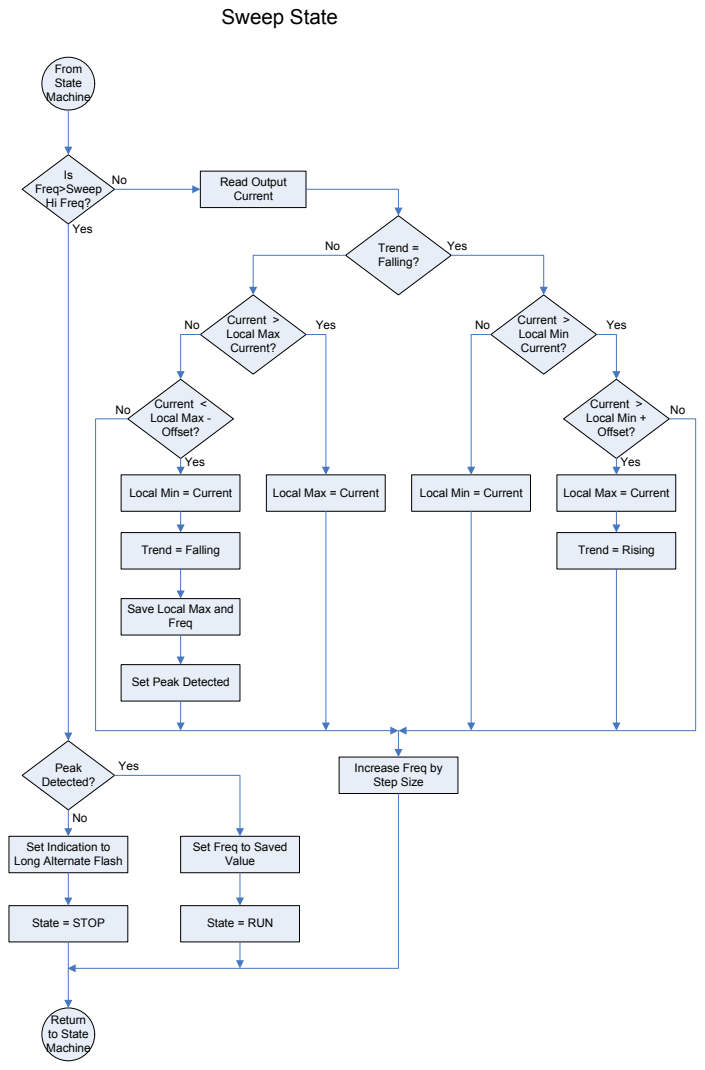
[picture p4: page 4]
State Machine; Return to State Machine; Is Freq>Sweep Hi Freq?; Read Output Current; Trend = Falling?; Current > Local Max Current?; Current > Local Min Current?; Local Min = Current; Local Max = Current; Freq; Peak Detected?; State = RUN; Current < Local Max - Offset?; Current > Local Min + Offset?; Trend = Falling; Trend = Rising; Yes; State = STOP

Save Local Max and

Set Peak Detected

Increase Freq by
Step Size

Set Indication to
Long Alternate Flash

Set Freq to Saved
Value

# Run State

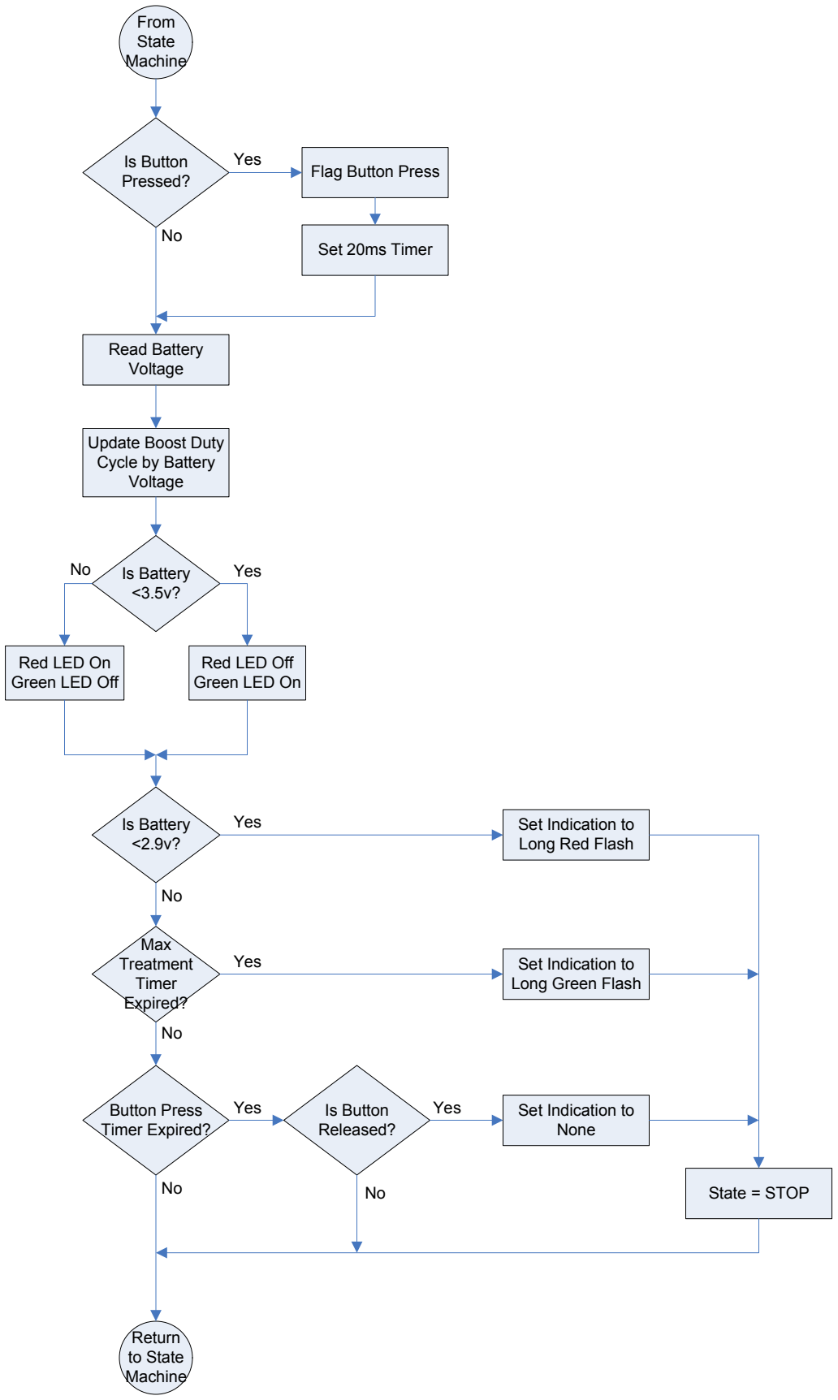
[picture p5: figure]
State Machine; Return to State Machine; Read Battery Voltage; Update Boost Duty Cycle by Battery Voltage; Is Battery <3.5v?; Red LED Off Green LED On; Red LED On Green LED Off; Is Button; Pressed?; Flag Button Press; Set 20ms Timer; Button Press Timer Expired?; Is Button Released?; Is Battery <2.9v?; Max Treatment Timer Expired?; Set Indication to None; Set Indication to Long Green Flash; Set Indication to Long Red Flash; State = STOP; Yes

# Stop State

# Indicate State

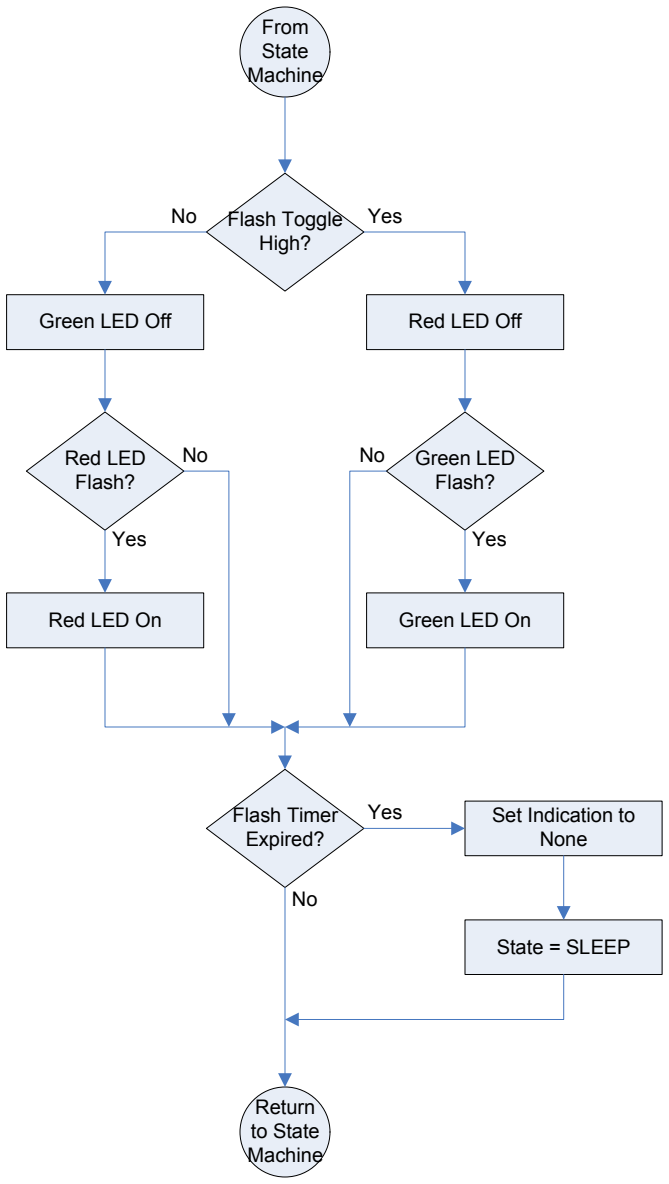
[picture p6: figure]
State Machine; Return to State Machine; Flash Toggle High?; Green LED Off; Red LED Off; Red LED Flash?; Green LED Flash?; Red LED On; Green LED On; Flash Timer Expired?; Set Indication to None; State = SLEEP; Yes

# Sleep State

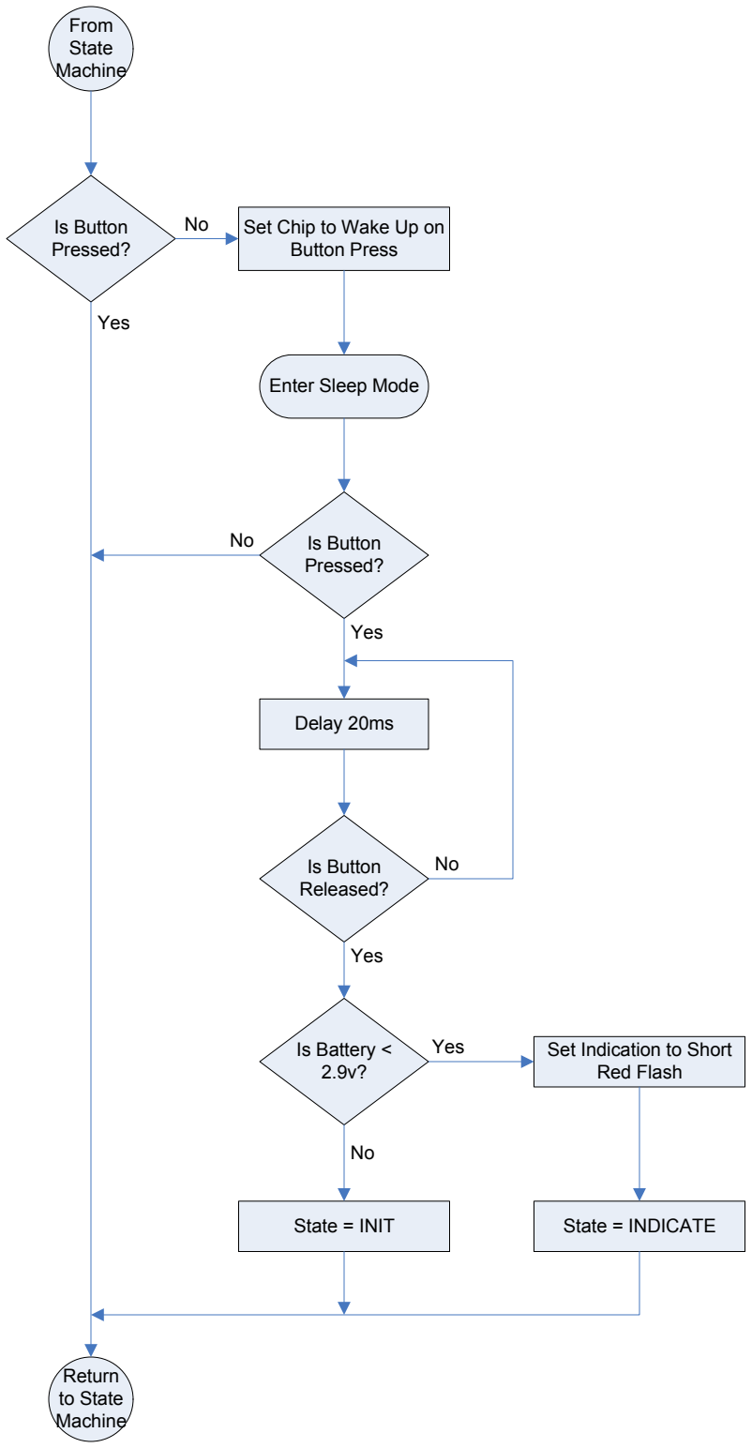
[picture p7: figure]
State Machine; Return to State Machine; Set Chip to Wake Up on Button Press; Enter Sleep Mode; Is Button Pressed?; Is Button Released?; State = INIT; State = INDICATE; Is Battery < 2.9v?; Set Indication to Short Red Flash; Delay 20ms; Yes

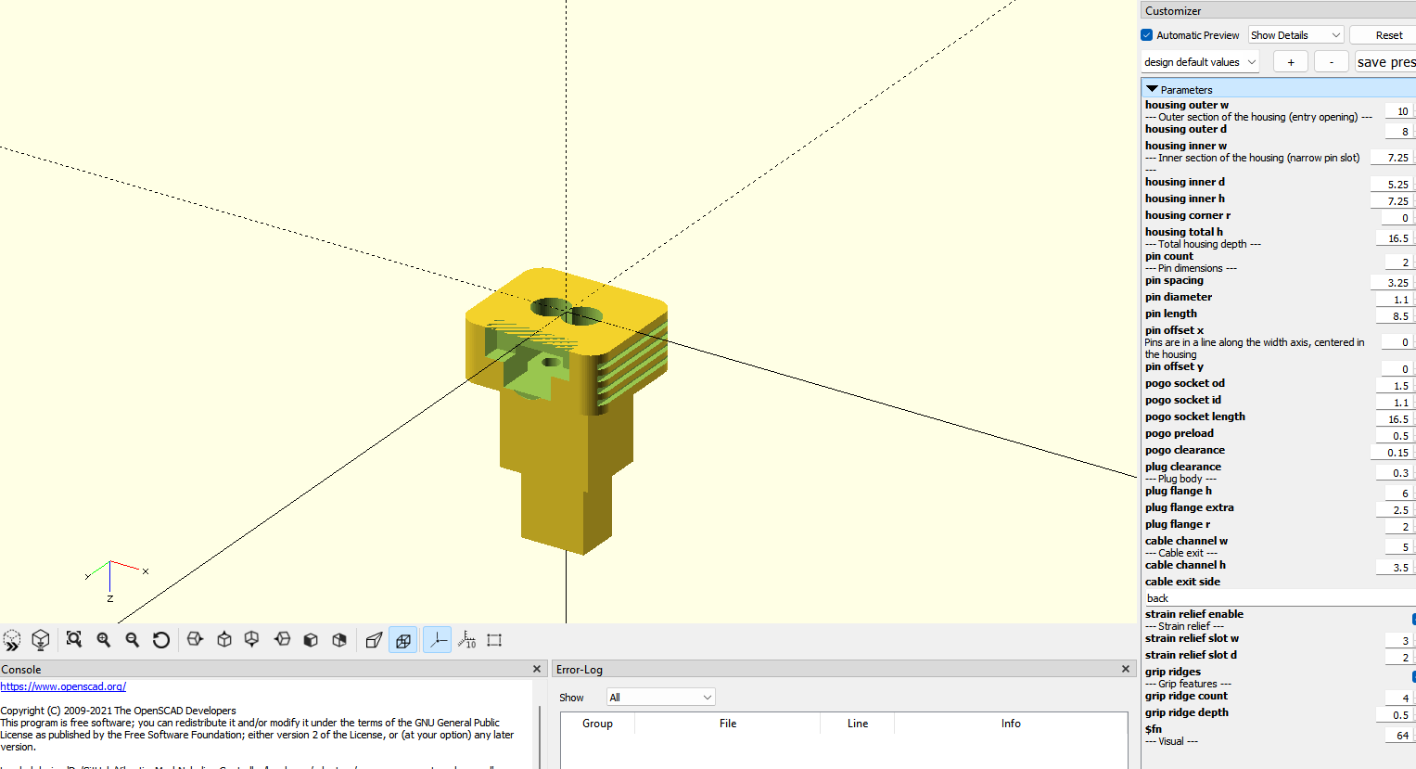
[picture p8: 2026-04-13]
connector_plug.png

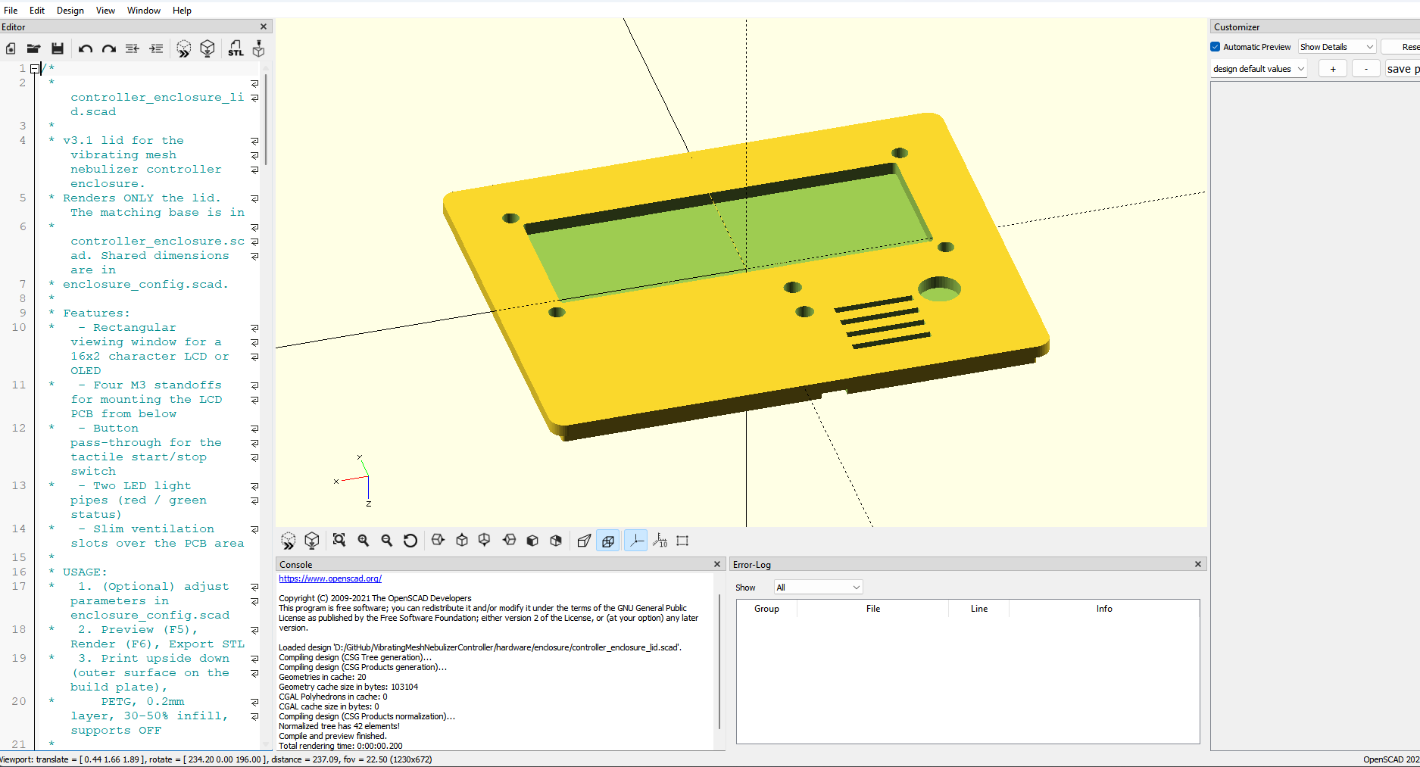
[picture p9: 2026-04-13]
nimbus_enclosure_lid.png

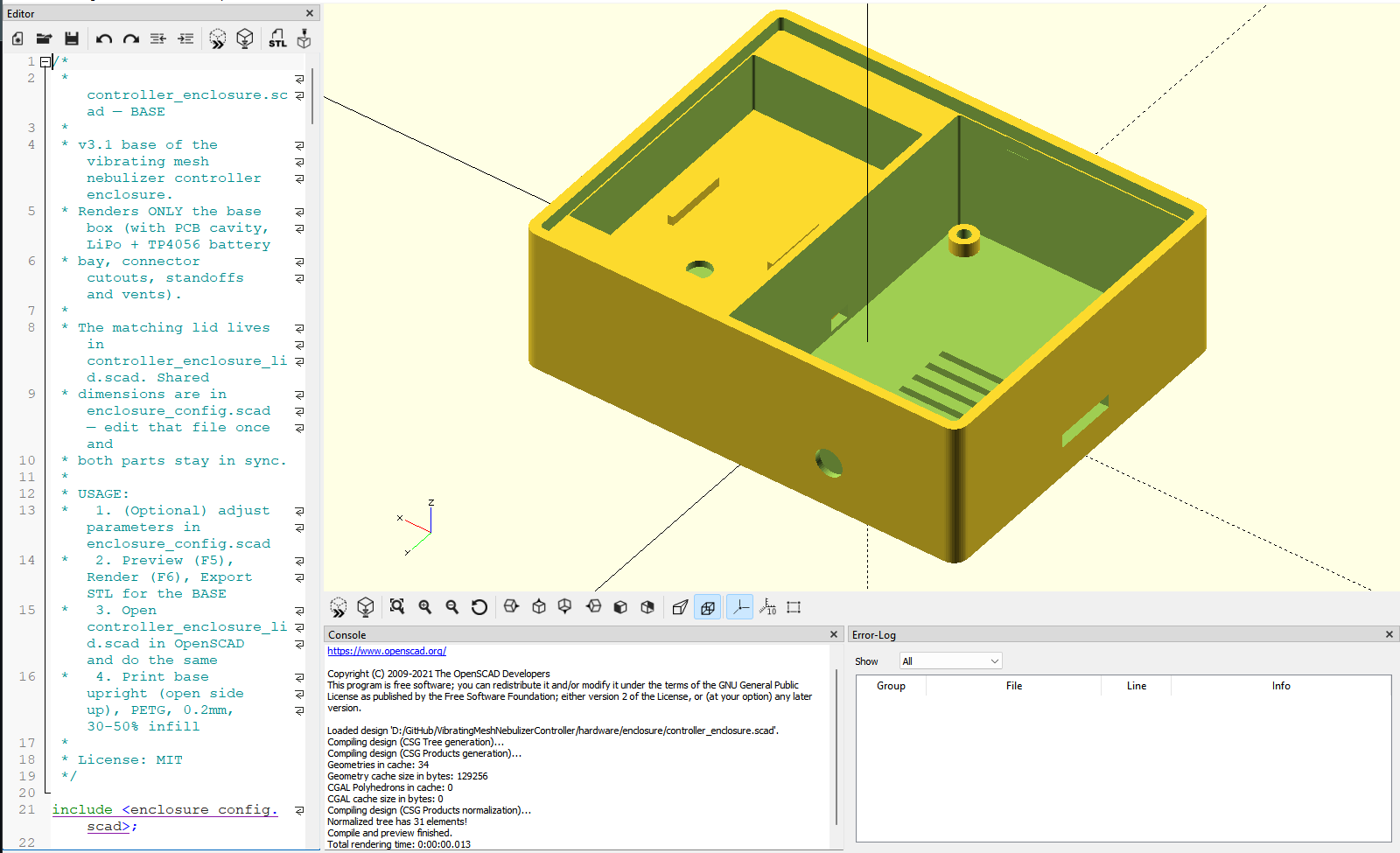
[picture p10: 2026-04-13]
nimbus_enclosure.png

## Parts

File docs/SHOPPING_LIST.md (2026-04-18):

# Nimbus Nebulizer Controller — Shopping List

Everything you need to build one Nimbus controller, organised by
supplier so you can copy/paste a cart. Quantities are for a **single
finished unit**, with a "5-pack" column for the JLCPCB minimum
batch (build one, keep spares).

**Read [DISCLAIMER.md](../DISCLAIMER.md) before ordering anything.**

---

## TL;DR — Cheapest Path (≈ $40 + programmer)

If you already own a soldering iron and a 3D printer:

| Source | Spend | What you get |
|---|---|---|
| JLCPCB (PCB + SMT assembly) | ~$50–80 | 5 populated boards |
| Amazon / AliExpress | ~$20–30 | LiPo, TP4056 pack, boost pack, LCD, pogos, cables |
| Home 3D printer | ~$3 | Enclosure + connector plug (PETG) |
| DigiKey (one-time) | ~$35 | MPLAB Snap programmer |
| **First-build total** | **~$80–115** | Programmer is reusable forever |
| **Per-board after first build** | **~$15–25** | Because the programmer is amortised |

Compare to an Aerogen Pro-X: **$2,700 out of pocket**.

---

## 1. PCB + SMT Assembly (JLCPCB)

You upload the gerbers + BOM + CPL once. JLCPCB ships populated boards.
See [JLCPCB_ORDERING_GUIDE.md](JLCPCB_ORDERING_GUIDE.md) for the full
walk-through.

| Item | Qty | LCSC / JLCPCB P/N | Unit | 5-pack |
|---|-----|---|---|---|
| PCB fab, 2-layer FR4, HASL | 5 | (gerbers) | – | $2–5 |
| SMT assembly (all SMD parts on [BOM_TURNKEY.csv](BOM_TURNKEY.csv)) | 5 | (BOM+CPL) | – | $40–75 |
| PIC16F1713-I/SO | 1 | **C507376** | ~$1 | on BOM |
| IRLML0100TRPBF MOSFET | 1 | **C414017** | ~$0.20 | on BOM |
| Inductor 150 µH (SMD 1210/1812) | 2 | **C341521** | ~$0.30 | on BOM |
| Cap 4.7 nF 200 V C0G 1206 | 1 | **C106225** | ~$0.10 | on BOM |
| Cap 0.1 µF 100 V 1206 | 1 | **C307331** | – | on BOM |
| 1N4148WS SOD-323 | 1 | **C81598** | – | on BOM |
| SS14 Schottky | 1 | **C2480** | – | on BOM |
| All 0603 R/C (1.8 Ω, 4.7 kΩ, 10 kΩ, 110 kΩ, 360 kΩ, 270 Ω, 100 Ω, 0.1 µF) | qty per BOM | see BOM | – | on BOM |
| 0603 SMD LED red + green | 1 + 1 | **C84256 / C72043** | – | on BOM |
| JST-PH TH header 2-pin (BAT IN) | 1 | **C265061** | – | on BOM |
| JST-XH TH header 2-pin (cup + boost in) | 2 | **C158012** | – | on BOM |
| 1×5 pin header (ICSP) | 1 | **C358687** | – | on BOM |
| 1×4 pin header (LCD) | 1 | **C124378** | – | on BOM |
| Tactile switch 6×6 mm | 1 | **C318884** | – | on BOM |

> **The single most commonly miscategorised part is C7 = 4.7 nF
> (not µF). 200 V C0G. If JLCPCB flags it as out-of-stock, pick an
> exact-spec substitute; don't accept a µF replacement.**

---

## 2. Amazon / AliExpress — User-Supplied Parts

These plug into the PCB after you receive it. Many ship in multi-packs,
so **a 5-board batch needs ~5 of most of these** — order once, sit on
the spares.

### Core plug-ins

| Item | Qty/unit | Qty for 5 units | How to search | Known SKU | Cost |
|---|---:|---:|---|---|---|
| MT3608 (or XL6009) boost module | 1 | 5 (comes in 5-packs) | `MT3608 boost module 5 pack` | — | $5 / 5-pack |
| 1S LiPo 103450 pouch, ≥ 2000 mAh, JST-PH pigtail | 1 | 5 | `103450 2000mAh LiPo JST` | **Amazon B07BTWK13N** | $8–12 |
| TP4056 + DW01A USB-C charger module | 1 | 15 (cheapest pack) | `TP4056 Type-C DW01A` | **Amazon B0CWNXKR4X** | $0.50 ea in 15-pack |
| 16×2 character display (pick one of A/B/C below) | 1 | 5 | see display section | — | $3–28 |
| USB-C cable | already own | – | – | – | $0 |

### Cables and connectors

| Item | Qty/unit | Qty for 5 units | How to search | Cost |
|---|---:|---:|---|---|
| JST-XH 2-pin **pre-crimped** pigtail, 150 mm | 2 (boost + cup) | 10 | `JST XH 2 pin pigtail 150mm` — most packs include 10 | $3 / 10-pack |
| JST-PH 2-pin **pre-crimped** pigtail, 100 mm | 1 (battery) | 5 | `JST PH 2 pin pigtail 100mm` | $3 / 10-pack |
| 4-wire female-female Dupont ribbon, ≥ 100 mm (LCD I²C) | 1 | 5 | `Dupont jumper wire 4-pin female 100mm` | $3 / 40-pack |

> Buying **pre-crimped** pigtails saves ~$40 of crimp-tool spend per
> first-timer. Only place you need to solder is the pogo pin tails in
> the connector plug.

### Mechanical

| Item | Qty/unit | Qty for 5 units | How to search | Cost |
|---|---:|---:|---|---|
| P75-B1 pogo pins (receptacle + plunger) | 2 | 10 (50-pack) | `P75-B1 pogo pin 50 pack` | ~$3 |
| M2.5 × 6 mm panhead machine screws (PCB mount) | 4 | 20 | `M2.5 x 6mm Phillips screw kit` | $5 / assortment |
| M3 × 6 mm panhead machine screws (LCD mount) | 4 | 20 | `M3 x 6mm Phillips screw kit` | $5 / assortment |
| Double-sided 3M foam tape (TP4056 + LiPo hold-down) | ~5 cm | – | `3M foam tape 3mm thick` | $3 |
| Cable zip ties, 100 mm, small (strain relief) | 1 | 5 | `small zip ties 100mm` | $2 / 100-pack |

### Bench / service parts (strongly recommended to have on hand)

| Item | Why | Search | Cost |
|---|-----|---|---|
| MG Chemicals 422B conformal coating spray | Protects PCB against saline mist | `MG 422B conformal coating 340g` | ~$14 |
| Isopropyl alcohol ≥ 99 % | Clean flux, clean pogo pins, clean mesh | `99% isopropyl alcohol 500ml` | ~$10 |
| Pre-saturated IPA swabs | Weekly nursery cleaning | `IPA swabs 99% 100 pack` | ~$6 |
| Aerogen Solo cups (medical supply) | 28-day life — always keep ≥ 2 spare | `Aerogen Solo cup` (medical supplier) | ~$40 ea |

---

## 3. DigiKey / Mouser — Precision Parts

Use DigiKey or Mouser for the few items where **provenance matters**:
the programmer, the optional character OLED, and the MCP2221 debug
bridge. They cost a little more but you don't risk a counterfeit on a
chip you're going to trust near a patient.

| Item | P/N | Where | Cost | Notes |
|---|-----|---|---|---|
| MPLAB Snap programmer | **PG164100-ND** (DigiKey) / PG164100 (Mouser) | DigiKey / Mouser | ~$35 | One-time. Flashes the PIC and every future rework. |
| Winstar WEH001602ALPP5N Character OLED 16×2 | **WEH001602ALPP5N00000** | DigiKey / Mouser | ~$22–28 | `LCD_IS_OLED = 1`. Recommended default. |
| Newhaven NHD-0216AW-IB3 Character OLED 16×2 (I²C native) | **NHD-0216AW-IB3** | DigiKey / Mouser | ~$25–32 | `LCD_IS_OLED = 1`. No backpack needed. |
| MCP2221A USB-UART/I²C bridge DIP-14 | **MCP2221A-I/P** | DigiKey / Mouser | ~$5 | Optional debug. Shows state transitions + sweep logs. |
| PICkit 4 (faster, better debug than Snap) | **PG164140** | DigiKey / Mouser | ~$60–90 | Pick one — Snap is enough for flashing. |

> Why not use the same supplier for *everything*? DigiKey prices for
> screws, zip-ties, foam tape, and generic LiPo cells are 3–5× Amazon /
> AliExpress. Split the cart: precision parts here, bulk commodities
> from the big marketplaces.

---

## 4. Pick-a-Display

You must pick exactly one of these. The firmware driver is identical
for all three; only `LCD_IS_OLED` in `firmware/src/config.h` changes.

| Option | P/N | Where | Cost | config.h | Pros | Cons |
|---|-----|---|---|---|---|---|
| **A — cheap** | Generic 1602 LCD + **LCD1602 IIC** PCF8574 backpack | Amazon / AliExpress | $3–5 | `LCD_IS_OLED = 0` | Cheapest; backlight readable in dark | Contrast sags under 3.7 V |
| **B — default** | **Winstar WEH001602ALPP5N** + PCF8574 backpack | DigiKey / Mouser | $22–28 | `LCD_IS_OLED = 1` | Rated 3.0–5.5 V; crisp at every battery level | More expensive |
| **C — integrated** | **Newhaven NHD-0216AW-IB3** | DigiKey / Mouser | $25–32 | `LCD_IS_OLED = 1` | I²C on-board, one fewer part | Slightly larger PCB |

The firmware **auto-probes** PCF8574 I²C addresses 0x27 (NXP) and 0x3F
(TI) at boot, so you don't need to know which variant your backpack is.

---

## 5. 3D Prints

You can print these at home (PETG recommended) or outsource to
JLCPCB's 3D-printing service. Set them all to ship in the same order
as the PCBs to save on freight.

| Part | File | Home filament | JLCPCB / service | Cost |
|---|---|---|---|---|
| Enclosure base | `hardware/enclosure/controller_enclosure.scad` → STL | PETG, 0.2 mm, 30 % infill | MJF nylon or SLA | $2–5 |
| Enclosure lid | `hardware/enclosure/controller_enclosure_lid.scad` → STL | PETG, 0.2 mm, 30 % infill | MJF nylon or SLA | $2–5 |
| Connector plug (Aerogen Solo) | `hardware/adapters/aerogen_connector_plug.scad` → STL | **SLA resin** (best) or PETG 0.12 mm layers | SLA resin | $1–3 |
| Universal adapter (other cups) | `hardware/adapters/universal_adapter.scad` → STL | PETG | SLA | $1–3 |

> Render STL from OpenSCAD GUI (`F6` → File > Export > STL) or:
> `openscad -o part.stl path/to/part.scad`.

---

## 6. One-Unit Build Checklist (copy/paste into a note app)

```text
[ ] Gerbers + BOM + CPL uploaded to JLCPCB (5 boards, SMT assembly on)
[ ] MT3608 boost module 5-pack
[ ] 1S LiPo pouch 103450 2000 mAh with JST-PH pigtail
[ ] TP4056 + DW01A USB-C charger (15-pack)
[ ] 16x2 display (pick: LCD $3 / Winstar OLED $25 / Newhaven $28)
[ ] JST-XH 2-pin pigtails, 150 mm (10-pack)
[ ] JST-PH 2-pin pigtails, 100 mm (10-pack)
[ ] 4-pin Dupont F-F ribbon, 100 mm (40-pack)
[ ] P75-B1 pogo pins (50-pack)
[ ] M2.5 x 6mm + M3 x 6mm screw assortment
[ ] 3M foam tape
[ ] 100 mm zip ties
[ ] MG Chemicals 422B conformal coating
[ ] Isopropyl alcohol 99% + swabs
[ ] MPLAB Snap (PG164100-ND, one-time, reuse forever)
[ ] Download MPLAB X IDE + XC8 (free)
[ ] STL files rendered from OpenSCAD for base + lid + connector plug
[ ] ≥ 2 Aerogen Solo cups on hand (medical supply)
```

---

## 7. Batch Build (5 Units) Checklist

5 complete controllers + spares. JLCPCB minimum order is 5 anyway, so
this is the natural sweet spot.

- 1 × JLCPCB order (5 assembled PCBs)
- 1 × MT3608 5-pack
- 5 × LiPo 103450 cells
- 1 × TP4056 15-pack (10 left for future builds or giveaways)
- 5 × displays of your chosen option
- 1 × each cable multi-pack (covers all 5 builds)
- 1 × pogo pin 50-pack
- 1 × screw assortment
- 1 × MPLAB Snap (reused across all 5)
- 5 × printed enclosure bases / lids / connector plugs
- 5 × Aerogen Solo cups on hand (plus 2 rotating spares)

---

## 8. Notes on Sourcing Safely

- **Always verify LiPo polarity with a multimeter** before plugging in.
  The JST-PH keying on the PCB prevents reversal, but cheap cells ship
  with the wrong wire colours occasionally.
- **Do not** buy "Aerogen-compatible" cups from AliExpress. The
  resonant frequency and piezo specs can differ enough to damage the
  cup or the controller. Use real Aerogen Solo cups from a medical
  supplier.
- **PIC16F1713** should come from Microchip's authorised channel
  (DigiKey, Mouser, Arrow, or JLCPCB via LCSC). Counterfeit PICs do
  exist on eBay and AliExpress.
- When ordering 3D prints from a service, request **FDA-grade** or
  "medical-grade" resin only if the part contacts medication. The
  enclosure and connector plug do not, so standard PETG / MJF is fine.

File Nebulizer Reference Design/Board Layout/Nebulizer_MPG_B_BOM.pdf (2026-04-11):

Quantity | Digikey | Designator | Comment | Description | Value | Voltage
6 | BK-82-ND | B1, B2, B3 | AAA | Battery Holder AAA | AAA
5 | 1276-1936-1-ND | C1, C4, C11, C14, C15 | Cap - Ceramic | Capacitor | 0.1uF | 50V
1 | 490-5523-1-ND | C2 | Cap - Electrolytic | Polarized Capacitor (Radial) | 10uF | 25V
1 | | C3 | Cap - Ceramic | Capacitor | DNP | 50V
2 | 1276-2923-1-ND | C5, C8 | Cap - Ceramic | Capacitor | 0.1uF | 100V
2 | 1276-1960-1-ND | C6, C16 | Cap - Ceramic | Capacitor | 1500pF | 50V
1 | 399-11942-1-ND | C7 | Cap - Ceramic | Capacitor | 4.7nF | 200V
1 | 490-7209-1-ND | C9 | Cap - Ceramic | Capacitor | 2.2uF | 100V
1 | | C10 | Cap - Ceramic | Capacitor | DNP | 100V
1 | 1276-1169-1-ND | C12 | Cap - Ceramic | Capacitor | 1nF | 100V
1 | 1276-1009-1-ND | C13 | Cap - Ceramic | Capacitor | 10nF | 50V
1 | 1276-2296-1-ND | C18 | Cap - Ceramic | Capacitor | 47pF | 50V
1 | SS14E-TPMSCT-ND | D1 | Schottky | Schottky Diode | SS14 | 40V
1 | 1N4148WTPMSCT-ND | D2 | Diode Single | | 1N4148
1 | | D3 | Diode Single | | DNP
1 | 0603SFV100F/32-2CT-ND | F1 | 1A | Fuse | 1A
1 | 455-1611-ND | J1 | Header 1x2 | | B2B-EH-A
1 | SAM1035-03-ND | J3 | Header 1x3 | | HDR-2.54 Male 1x3
1 | H2959CT-ND | J4 | CON USB2.0 Mini_Micro | Connector USB Mini | USB2.0 MINI-B FEMALE
1 | 277-1273-ND | J5 | Header 1x2 | | TERMINAL 1x2 | 63V
1 | SRN6045-220MCT-ND | L1 | Bourns 33uH, 1.4A | Inductor | 22uH
2 | SDR0603-151KLCT-ND | L2, L3 | Bourns 150uH, 320ma | Inductor | 150uH
1 | 754-1093-1-ND | LD1 | LED DUAL 4 pin | LED | RED, GREEN
1 | 952-2372-ND | P1 | Header 6 | Header, 6-Pin
2 | IRLML6402PBFCT-ND | Q1, Q3 | Transistor MOS-P GSD | Transistor MOS | IRLML6402
1 | RJP020N06T100CT-ND | Q2 | RJP020N06T100 | N-Channel MOSFET | RJP020N06T100 | 60V
1 | IRLML0100TRPBFCT-ND | Q4 | IRLML0100 | N-Channel MOSFET | IRLML0100 | 100V
3 | RMCF0603FT10K0CT-ND | R1, R2, R19 | Resistor | Resistor | 10K
1 | | R3 | Resistor | Resistor | DNP
1 | RMCF0603JT100RCT-ND | R4 | Resistor | Resistor | 100
1 | RMCF0603FT221KCT-ND | R5 | Resistor | Resistor | 221K
2 | RMCF0603JT1K00CT-ND | R6, R10 | Resistor | Resistor | 1K
4 | RMCF0603FT4K70CT-ND | R7, R15, R16, R25 | Resistor | Resistor | 4.7K

1 | RMCF0603FT15K0CT-ND | R8 | Resistor | Resistor | 15K
1 | A109657CT-ND | R9 | Resistor - 1/2W | Resistor | 0.33
1 | | R11 | Resistor | Resistor - 3W | DNP
1 | RMCF0603FT110KCT-ND | R12 | Resistor | Resistor | 110K
1 | RMCF0603FT360KCT-ND | R13 | Resistor | Resistor | 360K
1 | RMCF0603JT10R0CT-ND | R14 | Resistor | Resistor | 10
2 | RMCF0603JT270RCT-ND | R17, R20 | Resistor | Resistor | 270
1 | RL16R1.8FCT-ND | R18 | Resistor - 1/2W | Resistor | 1.8
4 | RMCF0603FT47K0CT-ND | R22, R23, R24, R26 | Resistor | Resistor | 47K
1 | 450-1129-ND *** | S1 | SW Tact 6x6 | Tactile Switch, SPST; Thru-Hole; Vertical | FSM4JSMA
1 | PIC16F1713-I/SO-ND | U1 | PIC16(L)F1713_6 SOIC-28_SSOP-28_SPDIP-28 | PIC16F1713 | PIC16F1713-I/SO
1 | MCP2221-I/ST-ND | U2 | MCP2221 SOIC-14_TSSOP-14_PDIP-14 | | MCP2221

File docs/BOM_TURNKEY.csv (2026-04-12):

Quantity | Reference | Component | Value | JLCPCB P/N or Source | Package | Category | Notes
 |  |  |  |  |  |  | TURNKEY BUILD — JLCPCB-assembled PCB with pre-built modules.
 |  |  |  |  |  |  | Goal: minimize soldering. Only connections are plug-in connectors.
 |  |  |  |  |  |  | Estimated total cost: ~$25-40 for 5 assembled boards (with JLCPCB SMT assembly)
 |  |  |  |  |  |  | See docs/JLCPCB_ORDERING_GUIDE.md for step-by-step ordering instructions.
 |  | === JLCPCB-ASSEMBLED (on PCB — no soldering by you) ===
1 | U1 | PIC16F1713-I/SO | MCU | C507376 | SOIC-28 | Core IC | SOIC-28 variant (not DIP) — JLCPCB places this. Pre-flash firmware via ICSP after assembly.
 |  | --- OUTPUT STAGE (SMD on PCB) ---
2 | L2 L3 | Inductor | 150 uH | C341521 | SMD 1210 or 1812 | Output Stage | Output LC resonant circuit. Verify JLCPCB stock for 150uH SMD inductor >= 500mA
1 | C7 | Capacitor | 4.7 nF 200V | C106225 | 1206 C0G/NPO | Output Stage | LC resonant cap. CRITICAL value — do not substitute. Must be C0G/NPO type, >= 200V.
1 | C5 | Capacitor | 0.1 uF 100V | C307331 | 1206 | Output Stage | DC blocking cap to nebulizer
1 | R18 | Resistor | 1.8 ohm 1/4W | C269786 | 0805 | Output Stage | Output current sense
1 | Q4 | IRLML0100TRPBF | N-MOSFET | C414017 | SOT-23 | Output Stage | Output switching MOSFET. Low Rds(on) at 3.3V Vgs.
1 | R_GATE | Resistor | 100 ohm | C25803 | 0603 | Output Stage | Q4 gate resistor
 |  | --- FEEDBACK SENSING (SMD on PCB) ---
1 | D2 | 1N4148WS | Signal Diode | C81598 | SOD-323 | Feedback | Peak voltage detector
1 | R12 | Resistor | 110K 1% | C25797 | 0603 | Feedback | Peak voltage divider
1 | R13 | Resistor | 360K 1% | C105807 | 0603 | Feedback | Peak voltage divider
1 | C12 | Capacitor | 1 nF 50V | C46653 | 0603 | Feedback | Peak detector filter
1 | R19 | Resistor | 10K | C25804 | 0603 | Feedback | Voltage sense input
 |  | --- ADC INPUT FILTERING (SMD on PCB) ---
2 |  | Resistor | 4.7K | C25999 | 0603 | Filtering | ADC input filter (AN1 and AN2)
2 |  | Capacitor | 0.1 uF 50V | C14663 | 0603 | Filtering | ADC input filter
 |  | --- POWER & PROTECTION (SMD on PCB) ---
1 | F1 | Fuse | 1A | C262671 | 0603 | Protection | SMD resettable fuse (PTC)
1 | D_REV | SS14 | Schottky Diode | C2480 | SMA | Protection | Reverse polarity protection
 |  | --- MCU SUPPORT (SMD on PCB) ---
3 |  | Capacitor | 0.1 uF 50V | C14663 | 0603 | Decoupling | VDD bypass caps
1 |  | Resistor | 10K | C25804 | 0603 | MCU | MCLR pull-up
 |  | --- CONNECTORS (SMD/TH on PCB) ---
1 |  | JST-PH 2-Pin Header | Battery Input (BAT IN) | C265061 | Through-hole | Power | v3.1: replaces USB-C receptacle. Accepts LiPo pack via TP4056 BAT+ / BAT- wires. Keyed so you can't reverse polarity.
1 |  | JST-XH 2-Pin Header | Cup Output | C158012 | Through-hole | Output | Connects to nebulizer cup adapter via JST cable
1 |  | Pin Header 1x5 | ICSP | C358687 | Through-hole | Programming | For flashing firmware. Accessible through enclosure port.
1 |  | JST-XH 2-Pin Header | Boost Module Input | C158012 | Through-hole | Power | Connects to boost module output
1 |  | Pin Header 1x4 | LCD/OLED I2C | C124378 | Through-hole | UI | v3.1: 4-pin header (VCC/GND/SDA/SCL) for 16x2 character display on lid. Wired to RC4/RC5.
 |  | --- USER INTERFACE (TH on PCB) ---
1 | SW1 | Tactile Switch | 6x6mm | C318884 | Through-hole | UI | Start/stop button. Can use SMD variant if preferred.
1 |  | LED Red | 3mm or 0805 | C84256 | 0805 SMD | UI | Power/status indicator
1 |  | LED Green | 3mm or 0805 | C72043 | 0805 SMD | UI | Resonance lock indicator
2 |  | Resistor | 270 ohm | C25768 | 0603 | UI | LED current limiting
1 |  | Resistor | 10K | C25804 | 0603 | UI | Button pull-up
 |  | === USER-SUPPLIED (not on PCB — plug in or add separately) ===
1 |  | Boost Module | MT3608 or XL6009 | Amazon/eBay/AliExpress |  | External Module | ~$1-2. Set output to ~12V with trim pot before connecting. Plugs into JST header on PCB.
1 |  | LiPo Cell | 103450 1S 2000mAh | Amazon B07BTWK13N (smaller 803040 works too) |  | Power | v3.1: rechargeable 1S LiPo pouch cell. 103450 = ~52x34x10 mm fits the enclosure bay. Must have a JST-PH pigtail — if not wired, solder one on carefully. $8-12.
1 |  | Charging Module | TP4056 + DW01A w/ Type-C | Amazon B0CWNXKR4X (15-pack) |  | Power | v3.1: USB-C LiPo charger with built-in DW01A protection (over-charge, over-discharge, over-current). ~$0.50 ea in 15-pack. Mount on internal shelf in the battery bay.
1 |  | USB-C Cable | Charging | Any |  | Cable | Standard USB-C cable. Plugs into the TP4056 module for charging. ~$0 (you have one)
1 |  | LCD or OLED, 1602 | 16x2 character w/ I2C backpack | (A) Amazon LCD1602 I2C kit ~$3, or (B) Winstar WEH001602 + PCF8574 ~$25, or (C) Newhaven NHD-0216AW-IB3 ~$28 |  | UI | v3.1: 16x2 character display for status/battery/frequency. Option (A) is the cheap HD44780 LCD (LCD_IS_OLED=0). Options (B)(C) are character OLEDs with much nicer contrast and viewing angle (set LCD_IS_OLED=1). All three work with the same firmware driver.
1 |  | JST-XH 2-Pin Cable | Cup Adapter Cable | Amazon/DigiKey |  | Cable | Pre-made JST-XH pigtail cable. Connects PCB to cup adapter. ~$1 for a 5-pack.
1 |  | JST-PH 2-Pin Cable | Battery Pigtail | Amazon/DigiKey |  | Cable | Short JST-PH pigtail to go between TP4056 BAT pads and the PCB BAT IN header. ~$1 for a 10-pack. Many LiPo cells already ship with one attached.
1 |  | 4-Wire Dupont Cable | LCD I2C Ribbon | Amazon/DigiKey |  | Cable | 4-pin female-female Dupont jumper (VCC/GND/SDA/SCL), ~100mm. Connects the lid LCD to the PCB LCD header. ~$0.50.
1 |  | 3D Printed Adapter | Cup-specific | See hardware/adapters/ |  | Mechanical | Print from OpenSCAD files. Or order from JLCPCB 3D printing service.
2 |  | P75-B1 Pogo Pins |  | Amazon/AliExpress |  | Mechanical | Spring-loaded contacts for the cup adapter. ~$3 for a 50-pack.
1 |  | 3D Printed Enclosure Base |  | hardware/enclosure/controller_enclosure.scad |  | Mechanical | Print from OpenSCAD. Base only — v3.1 split from the lid.
1 |  | 3D Printed Enclosure Lid |  | hardware/enclosure/controller_enclosure_lid.scad |  | Mechanical | Print from OpenSCAD. Has the LCD viewing window and standoffs.
4 |  | M2.5x6mm Screws | PCB mount | Amazon/hardware store |  | Hardware | To mount PCB in enclosure
4 |  | M3x6mm Screws | LCD mount | Amazon/hardware store |  | Hardware | v3.1: mounts the LCD/OLED PCB to the four standoffs in the lid.
1 |  | MPLAB Snap or PICkit 4 | Programmer | DigiKey PG164100-ND |  | Programmer | One-time purchase ~$35. Needed to flash firmware onto the PIC16F1713.
 |  | === COST ESTIMATE (v3.1) ===
 |  | JLCPCB PCB fabrication (5 boards) |  | $2-5 |  |  | Min order 5 boards. Use the Gerber files from the PCB design.
 |  | JLCPCB SMT assembly (per board) |  | $8-15 |  |  | Depends on component count and stock. Basic parts are cheapest.
 |  | Boost module |  | $1-2 |  |  | MT3608 5-pack from Amazon ~$5
 |  | LiPo cell (1S 2000 mAh 103450) |  | $8-12 |  |  | v3.1: rechargeable — replaces AAAs
 |  | TP4056 Type-C charger |  | $0.50-2 |  |  | v3.1: comes in 15-packs, ~$0.50/ea
 |  | 16x2 LCD + I2C backpack |  | $3-5 |  |  | v3.1 default: cheap HD44780 LCD
 |  | (or) 16x2 character OLED |  | $20-30 |  |  | v3.1 upgrade: Winstar / Newhaven / Matrix Orbital
 |  | Cup adapter + pogo pins |  | $3-5 |  |  | 3D print + 2 pogo pins + JST cable
 |  | Enclosure (base + lid) |  | $2-5 |  |  | 3D print (PETG recommended)
 |  | USB-C cable |  | $0 |  |  | (you already have one)
 |  | Programmer (one-time) |  | $35 |  |  | MPLAB Snap — reusable for all future boards
 |  | TOTAL PER UNIT with LCD |  | ~$30-45 |  |  | Assembled PCB + boost + LiPo + TP4056 + LCD + adapter + enclosure
 |  | TOTAL PER UNIT with OLED |  | ~$45-70 |  |  | Same as above but swap LCD for character OLED
 |  | TOTAL FIRST BUILD |  | ~$75-105 |  |  | Add programmer cost. Boards come in pack of 5 so you have spares.

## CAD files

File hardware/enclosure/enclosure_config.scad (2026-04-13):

/*
 * enclosure_config.scad
 *
 * Shared parameters and helper modules for the v3.1 controller enclosure.
 * Included from both controller_enclosure.scad (base) and
 * controller_enclosure_lid.scad (lid) so that dimensions stay in one place.
 *
 * v3.1 changes over v3.0:
 *   - AAA compartment replaced with a LiPo + TP4056 charging bay
 *   - PCB cavity raised to clear the LCD backpack pins
 *   - New 16x2 character LCD window + mounting posts on the lid
 *   - USB-C aperture moved to the battery bay front wall (TP4056 charge port)
 *
 * License: MIT
 */

/* =====================================================================
 * PCB DIMENSIONS
 *
 * The JLCPCB turnkey board is a 2-layer ~50x70mm FR4 PCB. Increase
 * pcb_component_height if you add taller modules to the board — it
 * directly sets how much headroom the lid leaves above the PCB, and
 * therefore how much room the LCD I2C backpack has to hang down into.
 * ===================================================================== */

pcb_width            = 50.0;    // X — short edge
pcb_depth            = 70.0;    // Y — long edge
pcb_thickness        = 1.6;     // Standard FR4
pcb_component_height = 18.0;    // Tallest top-side component + clearance
                                // (v3.1 raised from 12 -> 18 to clear the
                                //  LCD I2C backpack hanging down from the lid)
pcb_bottom_clearance = 2.0;
pcb_corner_radius    = 2.0;

pcb_mount_holes      = true;
mount_hole_diameter  = 2.7;     // For M2.5 screws
mount_hole_inset_x   = 3.5;
mount_hole_inset_y   = 3.5;
mount_standoff_h     = 3.0;

/* =====================================================================
 * LIPO BATTERY BAY (replaces v3.0's 3xAAA holder)
 *
 * Default is a 1S 2000mAh 103450 pouch cell (~50 x 34 x 10 mm). Any
 * pouch cell up to these dimensions will drop in. If you substitute a
 * larger cell, widen lipo_d / lipo_w here and reprint.
 * ===================================================================== */

battery_enable   = true;

lipo_w           = 36.0;    // Cell width + clearance (cell is ~34mm)
lipo_d           = 54.0;    // Cell length + clearance (cell is ~52mm)
lipo_h           = 11.0;    // Cell thickness + clearance (cell is ~10mm)

/* =====================================================================
 * TP4056 CHARGING MODULE
 *
 * Small PCB with USB-C input, DW01A protection and TP4056 charger IC.
 * It sits ABOVE the LiPo on an internal shelf, with the USB-C socket
 * facing out through a cutout in the bay's front wall. Typical modules
 * are ~25 x 18 x 6 mm with the USB-C socket protruding ~2 mm.
 * ===================================================================== */

tp4056_enable    = true;
tp4056_w         = 22.0;    // Module PCB width + clearance
tp4056_d         = 28.0;    // Module PCB depth including USB-C protrusion
tp4056_h         =  7.0;    // Module thickness (PCB + USB-C socket)
tp4056_shelf_t   =  1.5;    // Shelf wall thickness between LiPo and module
tp4056_usbc_w    =  9.5;    // USB-C aperture width
tp4056_usbc_h    =  3.5;    // USB-C aperture height

// Total height of the battery bay (LiPo + shelf + TP4056 + clearance)
battery_bay_h    = lipo_h + tp4056_shelf_t + tp4056_h + 2.5;
battery_bay_w    = max(lipo_w, tp4056_w);
battery_bay_d    = max(lipo_d, tp4056_d);

battery_wall     = 1.8;     // Wall between battery bay and PCB cavity
battery_clearance= 0.8;     // Extra clearance inside the bay

/* =====================================================================
 * 16x2 CHARACTER LCD WITH I2C BACKPACK
 *
 * Standard HD44780 1602 module, PCF8574 backpack. Mounts to the lid on
 * four M3 standoffs with the glass viewable through a rectangular window.
 *
 * Default dimensions are for the most common JHD162A-type module. Measure
 * yours and adjust if needed — especially the mount-hole spacing.
 * ===================================================================== */

lcd_enable            = true;

lcd_pcb_w             = 80.0;   // LCD PCB width
lcd_pcb_d             = 36.0;   // LCD PCB depth
lcd_pcb_thickness     =  1.6;
lcd_backpack_drop     = 11.0;   // Distance backpack hangs below the LCD PCB

lcd_viewing_w         = 72.0;   // Cutout width (generous fit around the glass)
lcd_viewing_h         = 26.0;   // Cutout height

// LCD position on the lid. Because the LCD PCB (~80 mm wide) is nearly
// as wide as the whole enclosure, it must be centered on the ENCLOSURE
// (x = 0), not on the PCB cavity — otherwise the window and the left
// mount standoff fall off the edge of the lid and break the seal.
lcd_window_offset_x   =  0.0;   // Window center X (0 = enclosure center)
lcd_window_offset_y   = 12.0;   // Window center Y (+Y = toward rear wall)

// Mount holes (measured from LCD PCB center)
lcd_mount_dx          = 75.0;   // X spacing between hole centers
lcd_mount_dy          = 31.0;   // Y spacing between hole centers
lcd_mount_hole_dia    =  3.2;   // M3 clearance
lcd_standoff_od       =  6.0;   // Standoff outer diameter
lcd_standoff_h        =  4.0;   // Standoff height below lid inner surface

/* =====================================================================
 * ENCLOSURE ENVELOPE
 * ===================================================================== */

wall_thickness     = 2.5;
base_height_extra  = 2.0;
lid_lip_height     = 3.0;
lid_lip_clearance  = 0.3;

// --- PCB cavity ---
int_pcb_width  = pcb_width + 2.0;
int_pcb_depth  = pcb_depth + 2.0;
int_pcb_height = pcb_bottom_clearance + pcb_thickness + pcb_component_height + 2.0;

// --- Battery bay cavity ---
int_bat_width  = battery_enable ? battery_bay_w + battery_clearance * 2 : 0;
int_bat_depth  = battery_enable ? battery_bay_d + battery_clearance * 2 : 0;
int_bat_height = battery_enable ? battery_bay_h + battery_clearance     : 0;

// --- Overall internal envelope ---
int_width  = int_pcb_width + (battery_enable ? battery_wall + int_bat_width : 0);
int_depth  = max(int_pcb_depth, battery_enable ? int_bat_depth : 0);
int_height = max(int_pcb_height, int_bat_height);

// --- External envelope ---
ext_width  = int_width + wall_thickness * 2;
ext_depth  = int_depth + wall_thickness * 2;
ext_height = int_height + wall_thickness + base_height_extra;
corner_r   = pcb_corner_radius + 1.0;

// --- Section offsets (X is positive to the right) ---
pcb_offset_x = battery_enable ? -(int_bat_width + battery_wall) / 2 : 0;
bat_offset_x = battery_enable ?  (int_pcb_width + battery_wall) / 2 : 0;

/* =====================================================================
 * CONNECTORS AND OPENINGS
 * ===================================================================== */

// USB-C charging aperture on the TP4056 front edge
// (formerly a PCB-mounted USB-C receptacle; v3.1 charges through TP4056)
usb_c_enable   = true;
usb_c_width    = 9.5;
usb_c_height   = 3.5;

// Cable gland for the connector-plug pigtail (rear short edge, PCB side)
cable_enable        = true;
cable_hole_diameter = 6.0;
cable_z_offset      = mount_standoff_h + pcb_thickness + 3.0;

// ICSP programming header slot
icsp_enable    = true;
icsp_width     = 14.0;
icsp_height    = 3.0;
icsp_z_offset  = mount_standoff_h + pcb_thickness + 1.0;

// LCD cable slot between the PCB cavity and the lid-mounted LCD.
// The 4-wire I2C ribbon runs through this gap.
lcd_wire_slot_w  = 5.0;
lcd_wire_slot_h  = 3.0;

/* =====================================================================
 * USER INTERFACE (on the lid)
 * ===================================================================== */

// The LCD occupies the upper half of the lid; the button + LEDs
// live in the lower half, over the PCB area where the existing
// tactile switch and LED packages are mounted on the board.

button_enable   = true;
button_diameter = 8.0;
button_x        = pcb_offset_x - int_pcb_width/4;
button_y        = -int_depth/4 + 2.0;    // Pushed toward the rear wall

led_enable      = true;
led_diameter    = 3.5;
led_red_x       = pcb_offset_x + int_pcb_width/4;
led_red_y       = -int_depth/4 + 2.0;
led_green_x     = pcb_offset_x + int_pcb_width/4;
led_green_y     = -int_depth/4 + 10.0;

/* =====================================================================
 * VENTILATION
 * ===================================================================== */

vent_enable       = true;
vent_slot_width   = 1.5;
vent_slot_length  = 15.0;
vent_slot_count   = 4;
vent_slot_spacing = 4.0;

/* =====================================================================
 * VISUAL
 * ===================================================================== */

$fn = 48;

/* =====================================================================
 * SHARED HELPER MODULES
 * ===================================================================== */

module rounded_box(w, d, h, r) {
    linear_extrude(height=h)
        offset(r=r)
            offset(delta=-r)
                square([w, d], center=true);
}

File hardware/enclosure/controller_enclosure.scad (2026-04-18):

/*
 * controller_enclosure.scad — BASE
 *
 * v3.1 base of the vibrating mesh nebulizer controller enclosure.
 * Renders ONLY the base box (with PCB cavity, LiPo + TP4056 battery
 * bay, connector cutouts, standoffs and vents).
 *
 * The matching lid lives in controller_enclosure_lid.scad. Shared
 * dimensions are in enclosure_config.scad — edit that file once and
 * both parts stay in sync.
 *
 * USAGE:
 *   1. (Optional) adjust parameters in enclosure_config.scad
 *   2. Preview (F5), Render (F6), Export STL for the BASE
 *   3. Open controller_enclosure_lid.scad in OpenSCAD and do the same
 *   4. Print base upright (open side up), PETG, 0.2mm, 30-50% infill
 *
 * License: MIT
 */

include <enclosure_config.scad>;

/* =====================================================================
 * ENCLOSURE BASE
 * ===================================================================== */

module enclosure_base() {
    difference() {
        union() {
            // Main box
            rounded_box(ext_width, ext_depth, ext_height, corner_r);

            // Lid lip (raised rim for lid to sit on)
            translate([0, 0, ext_height])
                difference() {
                    rounded_box(ext_width, ext_depth, lid_lip_height, corner_r);
                    translate([0, 0, -0.1])
                        rounded_box(ext_width - wall_thickness * 2 + lid_lip_clearance * 2,
                                    ext_depth - wall_thickness * 2 + lid_lip_clearance * 2,
                                    lid_lip_height + 0.2,
                                    max(0.5, corner_r - wall_thickness + 0.5));
                }
        }

        // === Hollow out PCB cavity ===
        translate([pcb_offset_x, 0, wall_thickness])
            rounded_box(int_pcb_width, int_pcb_depth,
                        int_height + lid_lip_height + 1,
                        max(0.5, corner_r - wall_thickness));

        // === Hollow out battery + TP4056 bay ===
        if (battery_enable)
            translate([bat_offset_x, 0, wall_thickness])
                rounded_box(int_bat_width, int_bat_depth,
                            int_bat_height + lid_lip_height + 1,
                            max(0.5, corner_r - wall_thickness));

        // === Wire slot between battery bay and PCB cavity ===
        // Lets the TP4056 BAT+/BAT- output wires reach the PCB power rail
        // through a 5x3 mm slot just above the bay floor.
        if (battery_enable) {
            slot_x = pcb_offset_x + int_pcb_width/2 - 0.1;
            translate([slot_x, -2.5, wall_thickness + 1])
                cube([battery_wall + 0.2, 5.0, 3.0]);
        }

        // === Connector cutouts ===

        // TP4056 USB-C charging aperture on the BATTERY BAY front wall.
        // z_usbc is the center of the USB-C socket, which sits just above
        // the internal shelf that the TP4056 rests on.
        if (usb_c_enable && battery_enable) {
            z_usbc = wall_thickness + lipo_h + tp4056_shelf_t + tp4056_h/2;
            translate([bat_offset_x, -ext_depth/2 - 0.1, z_usbc])
                usb_c_cutout();
        }

        // Cable exit (rear short edge) — for the connector plug pigtail
        if (cable_enable)
            translate([pcb_offset_x, ext_depth/2 - wall_thickness/2,
                       wall_thickness + cable_z_offset])
                rotate([-90, 0, 0])
                    cylinder(d=cable_hole_diameter, h=wall_thickness + 1);

        // ICSP port (long edge, PCB side). Y=0 puts it at the PCB long-edge
        // midpoint, which is where the 5-pin programming header lives on the
        // JLCPCB turnkey board.
        if (icsp_enable)
            translate([-ext_width/2 - 0.1,
                       0,
                       wall_thickness + icsp_z_offset])
                icsp_cutout();

        // LCD I2C wire slot — small notch in the top lip so the LCD
        // ribbon can pass from the PCB cavity into the lid-mounted LCD
        // without pinching when the lid closes.
        if (lcd_enable)
            translate([pcb_offset_x + int_pcb_width/4 - lcd_wire_slot_w/2,
                       -ext_depth/2 + wall_thickness - 0.1,
                       ext_height - lcd_wire_slot_h])
                cube([lcd_wire_slot_w, wall_thickness + 0.2, lcd_wire_slot_h + lid_lip_height + 1]);

        // Ventilation slots on bottom
        if (vent_enable)
            vent_slots();
    }

    // PCB mounting standoffs
    if (pcb_mount_holes)
        pcb_standoffs();

    // Battery bay retaining ribs (LiPo)
    if (battery_enable)
        battery_ribs();

    // TP4056 internal shelf — a thin floor stuck to the bay walls at
    // z = lipo top, so the charging module sits above the pouch cell
    // and its USB-C socket aligns with the aperture in the front wall.
    if (battery_enable && tp4056_enable)
        tp4056_shelf();
}

/* =====================================================================
 * CONNECTOR CUTOUTS
 * ===================================================================== */

module usb_c_cutout() {
    // Rounded rectangle for USB-C
    rotate([-90, 0, 0])
        linear_extrude(height=wall_thickness + 0.2)
            offset(r=1)
                offset(delta=-1)
                    square([usb_c_width, usb_c_height], center=true);
}

module icsp_cutout() {
    // Small rectangle for programming header access
    rotate([0, 90, 0])
        linear_extrude(height=wall_thickness + 0.2)
            square([icsp_height, icsp_width], center=true);
}

/* =====================================================================
 * PCB STANDOFFS
 * ===================================================================== */

module pcb_standoffs() {
    standoff_od = mount_hole_diameter + 3.0;
    /* Sink each standoff base 0.05 mm into the floor so CGAL fuses them
     * to the enclosure body in the union — without the overlap each
     * standoff renders as its own disconnected volume. */
    overlap = 0.05;
    positions = [
        [pcb_offset_x - pcb_width/2 + mount_hole_inset_x,
         -pcb_depth/2 + mount_hole_inset_y],
        [pcb_offset_x + pcb_width/2 - mount_hole_inset_x,
         -pcb_depth/2 + mount_hole_inset_y],
        [pcb_offset_x - pcb_width/2 + mount_hole_inset_x,
         pcb_depth/2 - mount_hole_inset_y],
        [pcb_offset_x + pcb_width/2 - mount_hole_inset_x,
         pcb_depth/2 - mount_hole_inset_y]
    ];

    for (pos = positions) {
        translate([pos[0], pos[1], wall_thickness - overlap]) {
            difference() {
                cylinder(d=standoff_od, h=mount_standoff_h + overlap);
                translate([0, 0, -0.1])
                    cylinder(d=mount_hole_diameter, h=mount_standoff_h + overlap + 0.2);
            }
        }
    }
}

/* =====================================================================
 * LIPO RETAINING RIBS
 *
 * A pair of soft ribs cradles the pouch cell so it doesn't slide
 * around during handling. Pouch cells are fragile — make sure the
 * ribs are no taller than 2 mm and have a rounded top (OpenSCAD
 * $fn=48 + small cylinder at the tip if you want to refine further).
 * ===================================================================== */

module battery_ribs() {
    rib_h = 2.0;
    rib_w = 1.5;
    overlap = 0.05;     /* Sink into the floor so CGAL fuses the ribs */

    for (side = [-1, 1]) {
        translate([bat_offset_x + side * (lipo_w/2),
                   -lipo_d/4,
                   wall_thickness - overlap])
            cube([rib_w, lipo_d/2, rib_h + overlap]);
    }
}

/* =====================================================================
 * TP4056 SHELF
 *
 * A thin floor spanning the battery bay at z = lipo top. Holds the
 * TP4056 charging module above the pouch cell. Has a cutout through
 * which the battery wires pass to the module's B+/B- pads.
 * ===================================================================== */

module tp4056_shelf() {
    z_shelf = wall_thickness + lipo_h + 0.5;

    difference() {
        // Solid slab covering the bay footprint
        translate([bat_offset_x, 0, z_shelf])
            linear_extrude(height=tp4056_shelf_t)
                square([int_bat_width - 0.5, int_bat_depth - 0.5], center=true);

        // Wire pass-through hole toward the rear of the bay
        translate([bat_offset_x, int_bat_depth/4, z_shelf - 0.1])
            cylinder(d=5.0, h=tp4056_shelf_t + 0.2);
    }

    // Small locating ribs around the TP4056 PCB footprint so it
    // doesn't float around on top of the shelf. Sink the rib bases
    // 0.05 mm into the shelf so CGAL fuses them in the union.
    overlap = 0.05;
    for (side = [-1, 1]) {
        translate([bat_offset_x + side * (tp4056_w/2),
                   -tp4056_d/4,
                   z_shelf + tp4056_shelf_t - overlap])
            cube([1.2, tp4056_d/2, 2.0 + overlap]);
    }
}
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

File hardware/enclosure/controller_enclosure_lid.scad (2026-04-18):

/*
 * controller_enclosure_lid.scad
 *
 * v3.1 lid for the vibrating mesh nebulizer controller enclosure.
 * Renders ONLY the lid. The matching base is in
 * controller_enclosure.scad. Shared dimensions are in
 * enclosure_config.scad.
 *
 * Features:
 *   - Rectangular viewing window for a 16x2 character LCD or OLED
 *   - Four M3 standoffs for mounting the LCD PCB from below
 *   - Button pass-through for the tactile start/stop switch
 *   - Two LED light pipes (red / green status)
 *   - Slim ventilation slots over the PCB area
 *
 * USAGE:
 *   1. (Optional) adjust parameters in enclosure_config.scad
 *   2. Preview (F5), Render (F6), Export STL
 *   3. Print upside down (outer surface on the build plate),
 *      PETG, 0.2mm layer, 30-50% infill, supports OFF
 *
 * License: MIT
 */

include <enclosure_config.scad>;

/* =====================================================================
 * ENCLOSURE LID
 * ===================================================================== */

module enclosure_lid() {
    difference() {
        union() {
            // Outer lid plate
            rounded_box(ext_width, ext_depth, wall_thickness, corner_r);

            // Inner lip that drops into the base
            translate([0, 0, wall_thickness])
                rounded_box(ext_width - wall_thickness * 2,
                            ext_depth - wall_thickness * 2,
                            lid_lip_height,
                            max(0.5, corner_r - wall_thickness));

            // LCD mounting standoffs rise from the lid's inner surface
            if (lcd_enable)
                lcd_standoffs();
        }

        // === LCD viewing window ===
        // Centered on the ENCLOSURE (lcd_window_offset_x = 0 by default),
        // not on pcb_offset_x — the LCD is nearly as wide as the lid, so
        // biasing it toward the PCB cavity would push the window past the
        // left edge of the lid and break the perimeter seal.
        if (lcd_enable)
            translate([lcd_window_offset_x, lcd_window_offset_y, -0.1])
                linear_extrude(height=wall_thickness + 0.2)
                    offset(r=0.8)
                        offset(delta=-0.8)
                            square([lcd_viewing_w, lcd_viewing_h], center=true);

        // === LCD screw holes through the standoffs ===
        if (lcd_enable)
            lcd_mount_holes();

        // === Button hole ===
        if (button_enable)
            translate([button_x, button_y, -0.1])
                cylinder(d=button_diameter, h=wall_thickness + 0.2);

        // === LED windows ===
        if (led_enable) {
            translate([led_red_x, led_red_y, -0.1])
                cylinder(d=led_diameter, h=wall_thickness + 0.2);
            translate([led_green_x, led_green_y, -0.1])
                cylinder(d=led_diameter, h=wall_thickness + 0.2);
        }

        // === Lid vents over the PCB area (not the LCD) ===
        // Slotted across the lower half of the lid so mist deposits
        // can't accumulate in a concave pocket.
        if (vent_enable)
            for (i = [0:vent_slot_count-1]) {
                translate([pcb_offset_x - vent_slot_length/2,
                           -ext_depth/2 + wall_thickness + 6 + i * vent_slot_spacing,
                           -0.1])
                    cube([vent_slot_length, vent_slot_width, wall_thickness + 0.2]);
            }

        // === LCD wire slot (matches the base-side notch in the lip) ===
        if (lcd_enable)
            translate([pcb_offset_x + int_pcb_width/4 - lcd_wire_slot_w/2,
                       -ext_depth/2 + wall_thickness - 0.1,
                       wall_thickness - 0.1])
                cube([lcd_wire_slot_w,
                      wall_thickness + 0.2,
                      lid_lip_height + 0.3]);

        // === Label recess — small "VMN" text on the OUTER lid face ===
        // The lid is printed upside down (outer face on the build plate),
        // so the outer face is at z = 0 in the model. Recess the text from
        // there into the plate so it's visible after flipping. The previous
        // version recessed at z = wall_thickness - 0.4, which put the text
        // on the INNER face and made it invisible from outside.
        translate([pcb_offset_x, -ext_depth/2 + 6, -0.1])
            linear_extrude(height=0.5)
                text("VMN", size=4.5, halign="center", valign="center",
                     font="Liberation Sans:style=Bold");
    }
}

/* =====================================================================
 * LCD MOUNTING STANDOFFS
 *
 * Four cylindrical posts that rise from the inside of the lid. The
 * LCD PCB bolts up into these with short M3 screws from below.
 * Keep the posts comfortably inside the inner lip so they clear the
 * base walls when the lid drops on.
 * ===================================================================== */

module lcd_standoffs() {
    /* Start the standoff base 0.05 mm INSIDE the lid plate (not at exactly
     * z = wall_thickness) so the CGAL union fuses standoff geometry to
     * the plate. Without the overlap each standoff renders as its own
     * disconnected volume — slicers may then drop the floating posts. */
    overlap = 0.05;
    for (sx = [-1, 1])
        for (sy = [-1, 1])
            translate([lcd_window_offset_x + sx * lcd_mount_dx/2,
                       lcd_window_offset_y + sy * lcd_mount_dy/2,
                       wall_thickness - overlap])
                cylinder(d=lcd_standoff_od, h=lcd_standoff_h + overlap);
}

module lcd_mount_holes() {
    for (sx = [-1, 1])
        for (sy = [-1, 1])
            translate([lcd_window_offset_x + sx * lcd_mount_dx/2,
                       lcd_window_offset_y + sy * lcd_mount_dy/2,
                       -0.1])
                cylinder(d=lcd_mount_hole_dia,
                         h=wall_thickness + lcd_standoff_h + 0.2);
}

/* =====================================================================
 * RENDER
 * ===================================================================== */

enclosure_lid();
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

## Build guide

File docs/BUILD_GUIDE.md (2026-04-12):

# Nimbus Build Guide — Turnkey (JLCPCB Pre-Assembled)

Complete guide to assembling the Nimbus Nebulizer Controller from a JLCPCB pre-assembled PCB.

**Read [DISCLAIMER.md](../DISCLAIMER.md) before starting.**

---

## What You're Building

A controller that drives the piezoelectric ring inside an Aerogen Solo nebulizer cup. The circuit has two main stages:

1. **Boost converter** — a pre-built module (MT3608/XL6009) steps up 5V USB power to ~12V DC
2. **Output stage** — converts the DC into a high-voltage AC waveform via an LC resonant circuit, driven by the MCU's frequency sweep

The two exposed connector pins on the Aerogen Solo cup are simply the two leads of the PZT ring actuator. The controller scans 90-150 kHz to find the resonant frequency, then locks on.

---

## What You Need

### From JLCPCB

Order the pre-assembled PCB following [JLCPCB_ORDERING_GUIDE.md](JLCPCB_ORDERING_GUIDE.md). JLCPCB solders all surface-mount components. You receive a completed board ready for firmware programming.

### User-Supplied Parts (v3.1)

See [BOM_TURNKEY.csv](BOM_TURNKEY.csv) for the complete list. The key items you supply:

| Item | Source | Cost |
|---|---|---|
| MT3608 or XL6009 boost module | Amazon/AliExpress | ~$1-2 |
| 1S LiPo pouch cell, 2000 mAh (103450) | Amazon B07BTWK13N | ~$8-12 |
| TP4056 + DW01A Type-C charger | Amazon B0CWNXKR4X (15-pack) | ~$0.50-2 |
| 16x2 character display (LCD default, OLED optional) | see below | ~$3 (LCD) or ~$25 (OLED) |
| USB-C cable (charging) | Any | ~$0 (you have one) |
| JST-XH 2-pin cable (cup output) | Amazon/DigiKey | ~$1 |
| JST-PH 2-pin cable (battery pigtail) | Amazon/DigiKey | ~$1 |
| 4-wire Dupont ribbon (LCD) | Amazon/DigiKey | ~$0.50 |
| P75-B1 pogo pins (2) | Amazon/AliExpress | ~$3/50-pack |
| M2.5x6mm screws (4, PCB mount) | Amazon/hardware store | ~$1 |
| M3x6mm screws (4, LCD mount) | Amazon/hardware store | ~$1 |
| MPLAB Snap programmer | DigiKey PG164100-ND | ~$35 (one-time) |

#### Picking a Display

v3.1 supports any 16x2 character display with an HD44780-compatible
command set driven by a PCF8574 I2C backpack. Three popular choices:

| Option | Part | Cost | Notes |
|---|---|---|---|
| **A** | Generic 1602 LCD + "LCD1602 IIC" backpack | ~$3-5 | `LCD_IS_OLED = 0`. Works in the dark thanks to its backlight; contrast may be dim below ~3.7 V battery. |
| **B (default)** | Winstar WEH001602A + PCF8574 backpack | ~$22-28 | `LCD_IS_OLED = 1`. Character OLED with WS0010 controller. Rated 3.0-5.5 V — stays crisp at any battery level. |
| **C** | Newhaven NHD-0216AW-IB3 | ~$25-32 | `LCD_IS_OLED = 1`. Has I2C built in — no external backpack needed. |

The firmware driver is the same for all three; only the `LCD_IS_OLED`
flag in `firmware/src/config.h` changes. If you already have the PCB
and want to upgrade the display later, you can do so without any
hardware changes.

### 3D-Printed Parts

v3.1 splits the enclosure into separate base and lid files so you can
iterate on either without re-rendering the other.

| Part | File | Material |
|---|---|---|
| Connector plug | `hardware/adapters/aerogen_connector_plug.scad` | PETG or SLA resin |
| Enclosure base | `hardware/enclosure/controller_enclosure.scad` | PETG |
| Enclosure lid | `hardware/enclosure/controller_enclosure_lid.scad` | PETG |

Shared dimensions live in `hardware/enclosure/enclosure_config.scad` —
edit it once and both base and lid stay in sync.

Print settings: 0.2mm layer height, 30-50% infill, supports disabled
(both files are orientation-friendly).

### Tools

- MPLAB Snap or PICkit 4/5 programmer
- Computer with MPLAB X IDE and XC8 compiler (both free from Microchip)
- Multimeter
- Soldering iron (only for 2 pogo pin wire joints in the connector plug)
- Small Phillips screwdriver (for boost module trim pot)

---

## Assembly

### Step 1: Flash Firmware

1. Install MPLAB X IDE and XC8 compiler (free from Microchip)
2. Open the firmware project from `firmware/`
3. The default `config.h` is already set for the turnkey build (`BOOST_MODE = BOOST_MODE_MODULE`)
4. Connect the MPLAB Snap to the board's ICSP header (5-pin)
5. Click "Make and Program Device" in MPLAB X
6. Programming takes ~10 seconds

### Step 2: Set Boost Module Voltage

1. Connect the MT3608/XL6009 module's input to a 5V source (USB charger works)
2. Measure the output with a multimeter
3. Turn the trim pot until output reads **~12V**
4. Disconnect

### Step 3: Assemble Connector Plug

See [hardware/adapters/README.md](../hardware/adapters/README.md) for detailed instructions.

1. Print the connector plug from `aerogen_connector_plug.scad`
2. Insert P75-B1 pogo pins into the two channels
3. Solder short stranded wires to each pogo pin solder cup
4. Route wires through the cable channel
5. Crimp or solder wires to a JST-XH 2-pin plug
6. Test-fit with an Aerogen Solo cup — pins should compress when cup seats

### Step 4: Prepare the LiPo + TP4056 Bay (v3.1)

1. **Inspect the LiPo cell.** Check the JST-PH pigtail polarity with
   a multimeter — the red lead must be +, black must be -. Do NOT
   trust the wire colors on a cheap cell without verifying.
2. **Pre-charge the cell** by connecting USB-C to the TP4056 module
   with its BAT pads still disconnected. The red charging LED should
   light. Unplug USB.
3. **Solder two short (~50 mm) wires** from the TP4056 BAT+ / BAT-
   pads to a matching JST-PH 2-pin plug that will mate with the PCB's
   BAT IN header. Double-check polarity — the PCB BAT IN header is
   keyed but the solder pads on the TP4056 are not.
4. **Seat the LiPo** in the enclosure battery bay (flat on the floor).
5. **Drop the TP4056** onto the internal shelf above the cell, USB-C
   socket facing the front aperture. Light double-sided foam tape
   keeps it from rattling.

### Step 5: Mount the LCD/OLED on the Lid

1. Feed the 4-pin Dupont ribbon through the lid's LCD wire slot.
2. Connect one end to the LCD backpack: VCC → VCC, GND → GND,
   SDA → SDA, SCL → SCL.
3. Position the LCD PCB over the four standoffs inside the lid,
   glass side facing out through the viewing window.
4. Secure with four M3 x 6 mm screws.
5. Peel off any protective film from the glass only AFTER all
   screws are tight — it's easy to scratch before the bezel seats.

### Step 6: Final Assembly

1. **Mount PCB** in the enclosure base using 4x M2.5x6 mm screws
2. **Connect boost module** to the JST header labeled "BOOST IN"
3. **Connect connector plug** JST cable to the cup output header
4. **Connect the LiPo pigtail** from the TP4056 BAT pads to the
   PCB's BAT IN JST-PH header
5. **Connect the LCD ribbon** from the lid to the PCB's 1x4 LCD
   header (match VCC/GND/SDA/SCL)
6. **Close the lid** — the standoffs should seat cleanly on the
   lid lip. Give the ribbon some slack so it isn't pinched.

### Step 7: First Power-Up

1. **Do NOT connect a nebulizer cup yet**
2. **Charge the cell** — plug USB-C into the TP4056 aperture until
   the red charge LED on the module turns off (~1-2 hours)
3. **Unplug USB**. The display should show the splash:
   ```
   Nimbus Nebulizer
    Controller v3.1
   ```
   After ~1.5 s it switches to the status line:
   ```
   READY  128.5kHz
   Bat 98%  4.13V
   ```
4. Red LED should also illuminate (IDLE state)
5. Measure VBOOST on the boost module output — should read ~12V
6. Press the start button — LCD should show `SWEEP...` then either
   `RUN 128.5kHz MM:SS` or `ERR no cup`
7. After ~3 seconds with no cup it should error — this is correct
8. Fill an Aerogen Solo cup with **normal saline** (not medication)
9. Seat the cup in the connector plug
10. Press start — `RUN 128.5kHz 00:01` should appear and fine mist
    should start within seconds

---

## If No Mist

- Check that the boost module output reads ~12V
- Verify the pogo pins make contact (multimeter continuity from JST plug to cup pads)
- Try increasing `BOOST_TARGET_DAC` in `config.h` for higher drive voltage (carefully, in small steps)
- Ensure the Solo cup has liquid and the mesh is not clogged
- Connect UART debug for detailed diagnostics (see below)

---

## Adjusting Parameters

All tunable parameters are in `firmware/src/config.h`:

| Parameter | Default | Description |
|---|---|---|
| `SWEEP_FREQ_MIN_HZ` | 90000 | Lower bound of frequency sweep (Hz) |
| `SWEEP_FREQ_MAX_HZ` | 150000 | Upper bound of frequency sweep (Hz) |
| `SWEEP_STEP_HZ` | 500 | Frequency step size during sweep (Hz) |
| `BOOST_TARGET_DAC` | 16 | DAC value controlling boost voltage (0-31). **Start low.** |
| `TREATMENT_MODE` | `TREATMENT_MODE_CONTINUOUS` | `CONTINUOUS` runs until button/dry-cup, `TIMED` auto-stops |
| `TREATMENT_TIME_SEC` | 1800 | Treatment duration in TIMED mode (default 30 min) |
| `RESONANCE_THRESHOLD` | 100 | Minimum ADC reading to consider as resonance |
| `DRY_CUP_THRESHOLD` | 30 | ADC reading below which cup is considered empty |
| `FREQ_CACHE_ENABLED` | 1 | Save last frequency to flash for faster next startup |

---

## Power Supply (v3.1)

v3.1 uses a rechargeable 1S LiPo pouch cell charged through a
TP4056/DW01A USB-C module. There is no separate 5V rail — the MCU
and the boost module both run directly off the cell (3.0-4.2 V).

| Path | Voltage | Notes |
|---|---|---|
| **LiPo 1S** | 3.0-4.2 V (3.7 V nominal) | Powers MCU + boost module. Runtime ~3-5 treatments per charge. |
| **USB-C (TP4056)** | 5 V in → 4.2 V CV charge | Plug in to recharge. You can also run from USB while charging. |

The firmware continuously monitors battery voltage via the PIC's Fixed
Voltage Reference and shows percent + millivolts on the LCD. A soft
cutoff at 3.1 V warns the user and stops any running treatment before
the DW01A hardware protection (2.5 V) trips.

---

## Test Points and Debugging

If things aren't working, check these signals with a multimeter:

| Test Point | Expected Value | What It Means If Wrong |
|---|---|---|
| VDD (pin 20) | 4.5-5.0V DC | Power supply issue |
| VBOOST (module output) | ~12V DC | Boost module not set correctly |
| Red LED (RC0) | Solid red in IDLE | MCU not running |
| Green LED (RC1) | Solid green in RUNNING | Sweep failed to find resonance |

**UART debug output** is the most useful diagnostic. Connect a MCP2221 USB-UART bridge to the ICSP/debug header and open a terminal at 9600 baud. The firmware prints state transitions, sweep results, and resonance values.

---

## Safety Reminders

- **Start with normal saline** — never medication until operation is stable and repeatable
- **Don't overdrive the PZT** — start with lower DAC1 values and increase gradually
- **Monitor temperature** — if the Solo cup gets warm, you're overdriving it
- **The Solo cup has a 28-day intermittent life** — this doesn't change with a DIY controller
- **Keep away from ventilator circuit** during testing — only integrate once reliable

---

## Nursery Environment: Making It Last

This device will live in a nursery with a child who needs 6+ nebulizer treatments per day. That's 2,000+ power cycles per year, with exposure to saline mist, medication, and the general chaos of a nursery. Here's how to make it survive.

### Moisture Protection

Saline and medication mist will drift. Over time, salt deposits corrode exposed copper.

- **Conformal coating spray** (MG Chemicals 422B or similar, ~$12/can) — spray a thin coat over the assembled PCB. Mask the button, LEDs, and connectors before spraying.
- **Keep the controller away from the mist output.** Position the controller at least 30 cm (12") from the cup, or below it where mist doesn't settle. The flexible cable between the connector plug and enclosure makes this easy.
- **Wipe down weekly** with a dry cloth. If salt deposits accumulate on the enclosure, dampen the cloth slightly.

### Strain Relief

The cable between the connector plug and controller will flex with every cup change. The JST connectors and cable glands in the enclosure design handle this, but:

- **Use stranded wire** (not solid core) for the connector cable
- **Leave a service loop** inside the enclosure
- **Keep cable length under 50 cm** — longer cables pick up noise at 100+ kHz

### Spares to Keep on Hand

| Item | Why | Cost |
|---|-----|---|
| Aerogen Solo cups (2-3 extra) | 28-day life, you never want to run out | ~$40 each |
| Pre-programmed spare PCB | You ordered 5 from JLCPCB — keep one as backup | ~$0 (already have it) |
| Spare boost module | They're cheap, keep one ready | ~$2 |
| Spare pogo pins | In case one stops springing back | ~$0.10 each |

### When Something Goes Wrong

| Symptom | Likely Cause | Fix |
|---|---|-----|
| Intermittent mist | Pogo pin not making contact | Clean pins with isopropyl alcohol, check continuity |
| No mist, green LED on | VBOOST too low or cup is dry | Check boost module voltage, refill cup |
| No mist, red LED blinking | Sweep can't find resonance | Check pogo pin contact, try fresh cup |
| Takes multiple presses to start | Button issue | Check button connection |
| Weaker mist than usual | VBOOST drifting | Re-measure and adjust boost module trim pot |

---

## Visual Guides

See **[DIAGRAMS.md](DIAGRAMS.md)** for visual diagrams of:
- Controller state machine
- Circuit block diagram and signal flow
- Frequency sweep algorithm (with caching fast path)
- Treatment session flow with dry-cup and re-sweep logic

---

## Connector Plug and Enclosure

- **[Connector Plug](../hardware/adapters/aerogen_connector_plug.scad)** — Plugs onto the Aerogen Solo cup's 2-pin connector, with flexible cable to the controller
- **[Universal Adapter](../hardware/adapters/universal_adapter.scad)** — Configurable adapter for OMRON, PARI, Philips, and other cups
- **[Enclosure](../hardware/enclosure/controller_enclosure.scad)** — Houses the PCB with battery compartment, USB-C port, and cable gland for the connector cable

See [hardware/adapters/README.md](../hardware/adapters/README.md) for measurement guides and assembly instructions.

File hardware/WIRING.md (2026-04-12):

# Wiring Reference — PIC16F1713 DIP-28 Breadboard Build

Pin-by-pin wiring guide for the AN2265-based vibrating mesh nebulizer controller.

---

## PIC16F1713-I/SP (DIP-28) Pinout

```
                  ┌────────────┐
   MCLR/RE3  1 ──┤            ├── 28  RB7/ICSPDAT
    AN0/RA0  2 ──┤            ├── 27  RB6/ICSPCLK
    AN1/RA1  3 ──┤            ├── 26  RB5/AN13
    AN2/RA2  4 ──┤            ├── 25  RB4/AN11
   AN3/RA3   5 ──┤            ├── 24  RB3/AN9
  CWG1A/RA4  6 ──┤ PIC16F1713 ├── 23  RB2/AN8
  CWG1B/RA5  7 ──┤   DIP-28   ├── 22  RB1/AN10
        VSS  8 ──┤            ├── 21  RB0/AN12/INT
   OSC1/RA7  9 ──┤            ├── 20  VDD
   OSC2/RA6 10 ──┤            ├── 19  VSS
        RC0 11 ──┤            ├── 18  RC7/RX
        RC1 12 ──┤            ├── 17  RC6/TX
   CCP1/RC2 13 ──┤            ├── 16  RC5/CWG1A
   NCO1/RC3 14 ──┤            ├── 15  RC4
                  └────────────┘
```

---

## Pin Assignments

| Pin | Name | Direction | Function | Connects To |
|-----|---|---|---|---|
| 1 | RE3/MCLR | Input | Master Clear / Programming | 10K pull-up to VDD + Programmer MCLR |
| 2 | RA0/AN0 | Input (Analog) | Boost current sense ADC | R9 junction via 4.7K filter resistor |
| 3 | RA1/AN1 | Input (Analog) | Output current sense ADC | R18 junction via 4.7K filter resistor |
| 4 | RA2/AN2 | Input (Analog) | Peak voltage detector ADC | R12/R13 voltage divider midpoint |
| 5 | RA3/AN3 | Input (Analog) | Boost voltage feedback ADC | R5/R8 voltage divider midpoint |
| 6 | RA4/CWG1A | Output | Boost MOSFET gate drive | Q2 gate via 100 ohm resistor |
| 7 | RA5/CWG1B | Output | (Complementary, unused) | Leave unconnected |
| 8 | VSS | Power | Ground | Ground rail |
| 9 | RA7/OSC1 | — | Unused (internal osc) | Leave unconnected |
| 10 | RA6/OSC2 | — | Unused (internal osc) | Leave unconnected |
| 11 | RC0 | Output | Red LED (power/error) | Red LED anode via 270 ohm to ground |
| 12 | RC1 | Output | Green LED (resonance lock) | Green LED anode via 270 ohm to ground |
| 13 | RC2/CCP1 | Output | PWM for boost control | Alternative boost drive (see firmware config) |
| 14 | RC3/NCO1 | Output | NCO frequency output | Q4 gate via 100 ohm resistor |
| 15 | RC4 | — | Unused | Leave unconnected |
| 16 | RC5 | — | Unused | Leave unconnected |
| 17 | RC6/TX | Output | UART TX (debug) | MCP2221 RX (optional) |
| 18 | RC7/RX | Input | UART RX (debug) | MCP2221 TX (optional) |
| 19 | VSS | Power | Ground | Ground rail |
| 20 | VDD | Power | +3.0-4.2V supply | LiPo + rail (directly from TP4056 BAT+) |
| 21 | RB0/INT | Input | Start/stop button | Tactile switch to GND + 10K pull-up to VDD |
| 22-26 | RB1-RB5 | — | Unused | Leave unconnected |
| 27 | RB6/ICSPCLK | Prog | Programming clock | Programmer PGC |
| 28 | RB7/ICSPDAT | Prog | Programming data | Programmer PGD |

Note on pin 14 (RC3): remains NCO1 output driving Q4.
Note on pins 15-16 (RC4, RC5): v3.1 reassigns these to the LCD/OLED
I2C bus — RC4 = SDA, RC5 = SCL. They run as open-drain (driven low
or released high) and are pulled up by the 4.7 kΩ resistors on the
PCF8574 backpack. See the LCD section below.

---

## Boost Converter Wiring

```
                                    D1 (1N5819)
  VDD (+4.5V) ──── L1 (22uH) ────┬────>|────── VBOOST Rail
                                  │
                              Q2 Drain          R5 (221K)
                              (RJP020N06)   VBOOST ──┤
                              Q2 Gate ◄── 100R ── RA4 (pin 6)     ├── AN3 (pin 5)
                              Q2 Source         R8 (15K)
                                  │                 ├── GND
                              R9 (0.33R)
                                  │             C2 (10uF) ┤├ GND
                                 GND            C9 (2.2uF) ┤├ GND
                                  │
                          (to AN0 via 4.7K + 0.1uF filter)
```

### Boost Voltage Feedback
The voltage divider R5/R8 scales VBOOST down to ADC range:
- V_adc = VBOOST x R8 / (R5 + R8) = VBOOST x 15K / 236K
- At VBOOST = 15V: V_adc = 0.95V (within 0-4.5V ADC range)

---

## Output Stage Wiring

```
                    L2 (150uH)
  VBOOST ──────────────┬──────────── Solo Contact A
                       │                    │
                   Q4 Drain             C7 (4.7nF)
                   (IRLML0100)              │
                   Q4 Gate ◄── 100R ── RC3 (pin 14)
                   Q4 Source            Solo Contact B
                       │                    │
                   R18 (1.8R)           L3 (150uH)
                       │                    │
                      GND              VBOOST
                       │
               (to AN1 via 4.7K + 0.1uF filter)
```

### Peak Voltage Detector
```
  Output Node ──── D2 (1N4148) ────┬──── R13 (360K) ────┬──── GND
                   (cathode →)     │                     │
                               C12 (1nF)            R12 (110K)
                                   │                     │
                                  GND              AN2 (pin 4)
```

---

## ICSP Programming Header

Connect your MPLAB Snap or PICkit to these 5 signals:

```
  Programmer          PIC16F1713
  ──────────          ──────────
  MCLR/VPP  ──────── Pin 1  (RE3/MCLR)
  VDD       ──────── Pin 20 (VDD)
  VSS/GND   ──────── Pin 8 or 19 (VSS)
  PGD/ICSPDAT ────── Pin 28 (RB7)
  PGC/ICSPCLK ────── Pin 27 (RB6)
```

The MPLAB Snap has a standard 8-pin header. Only these 5 pins are used. Check your programmer's pinout documentation for the exact header positions.

---

## Optional: UART Debug (MCP2221)

If you want serial debug output:

```
  PIC16F1713            MCP2221-I/P (DIP-14)
  ──────────            ────────────────────
  RC6/TX (pin 17) ───── RXD (pin 6)
  RC7/RX (pin 18) ───── TXD (pin 5)
  VDD (pin 20) ──────── VDD (pin 14)
  VSS (pin 8) ────────── VSS (pin 7)
                         USB D+ (pin 12) ── USB cable
                         USB D- (pin 11) ── USB cable
```

The MCP2221 appears as a USB serial port on your computer. Use any terminal program (PuTTY, minicom, screen) at 9600 baud 8N1 to see debug output.

---

## Power Supply (v3.1 — LiPo + TP4056)

v3.1 drops the 3x AAA / USB dual-path in favour of a rechargeable
1S LiPo pouch cell charged through a TP4056/DW01A module. USB-C on
the TP4056 module is the user-facing charging port; the old
PCB-mounted USB-C receptacle is removed.

```
  USB-C (5V in)                                       VBOOST (~12V)
       │                                                    ▲
       ▼                                                    │
  ┌─────────┐      ┌─────────┐      ┌─────────┐     ┌──────────┐
  │ TP4056  │ BAT+ │  LiPo   │ +    │  PCB    │ PWR │  MT3608  │
  │ charger │──────│ 1S 1S   │──────│ BAT IN  │─────│  boost   │
  │ + DW01A │ BAT- │ ~2000   │ -    │ (JST-2) │     │  module  │
  │ protect │──────│  mAh    │──────│         │     └──────────┘
  └─────────┘      └─────────┘      └─────────┘           │
                                           │               ▼
                                        VDD=Vbat       (output stage)
                                   (3.0-4.2V to MCU)
```

Key points:

- **MCU VDD tracks the battery voltage** (3.0 V to 4.2 V). The PIC16F1713
  is rated 1.8-5.5 V so this is well within spec.
- **Battery measurement needs no external parts.** The firmware enables
  the Fixed Voltage Reference at 2.048 V and reads it via ADC channel 31.
  Because the ADC reference is VDD, the ratio gives VDD directly:
  `Vbat_mV = 2048 * 1023 / adc_reading`. See `peripherals.c::battery_read_mv()`.
- **TP4056 protects the cell** against over-charge (4.2 V cutoff), over-
  discharge (2.5 V cutoff) and over-current / short. The firmware adds a
  second software cutoff at 3.1 V so the device warns and shuts down
  before the hardware protection trips and makes the pack look "dead".
- **Do not reverse the LiPo polarity.** The TP4056 does not have reverse
  protection on the BAT pads. Use a keyed JST-PH 2-pin connector.
- **USB and LiPo at the same time is fine** — when USB is connected,
  the TP4056 charges the cell and simultaneously powers the load.

### Optional: Bench Supply (Prototyping Only)

If you want to test the PCB without a LiPo, you can substitute a
bench supply directly on the BAT IN header:

```
  Bench (+) ──── BAT IN + (JST-2)
  Bench (-) ──── BAT IN -
  Set: 3.7 V nominal, current limit 800 mA
```

Disconnect the TP4056 module when doing this — feeding the BAT pads
while USB is live can damage the charger IC.

---

## LCD / OLED Wiring (v3.1)

A 16x2 character display (LCD or OLED, see `config.h::LCD_IS_OLED`)
mounts on the lid of the enclosure and connects to the PCB via a
4-wire ribbon:

```
  LCD Backpack (PCF8574)        PCB LCD Header (1x4)
  ────────────────────          ─────────────────────
  VCC  ────────────── VDD   (+3.3-4.2 V, same as MCU VDD)
  GND  ────────────── GND
  SDA  ────────────── RC4   (pin 15 — bit-bang I2C SDA)
  SCL  ────────────── RC5   (pin 16 — bit-bang I2C SCL)
```

- The PCF8574 backpack has 4.7 kΩ pull-ups to VCC on SDA/SCL, so no
  external pull-up resistors are needed.
- Bus speed is ~100 kHz, driven in software at 10 ms main-loop
  cadence. Refresh is ~2 Hz.
- The backpack I2C address is auto-detected between 0x27 (NXP
  PCF8574) and 0x3F (TI PCF8574A) at boot.
- Most 1602 character OLEDs (Winstar WEH001602, Newhaven NHD-0216AW,
  Matrix Orbital MOP-AO162) are pin-compatible with the same
  backpack and drop in with `LCD_IS_OLED = 1` in `config.h`.

---

## Breadboard Layout Tips

1. **Place the PIC in the center** — it has the most connections
2. **Keep boost components close together** — L1, Q2, D1, C2/C9 should be near each other to minimize parasitic inductance
3. **Keep output stage on one side** — L2, L3, Q4, C7 together, with short leads to the Solo cup connections
4. **Bypass caps as close to IC as possible** — the 0.1 uF caps on VDD should be right next to pin 20/8
5. **Star ground if possible** — route high-current ground returns (boost, output) separately from analog sense grounds
6. **Keep analog sense wires away from switching nodes** — the NCO output and boost switching are noisy; route ADC sense wires away from them

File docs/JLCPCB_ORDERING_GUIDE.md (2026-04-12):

# JLCPCB Ordering Guide — Pre-Assembled Nebulizer Controller

Step-by-step guide to ordering a fully assembled controller PCB from JLCPCB. This eliminates nearly all soldering — you receive a completed board, plug in a boost module and cup adapter, flash the firmware, and you're done.

**Read [DISCLAIMER.md](../DISCLAIMER.md) before building.**

---

## Overview

JLCPCB offers both PCB fabrication and SMT assembly. You upload design files, they manufacture the boards and solder all the surface-mount components. What you get back is a populated, tested PCB ready for firmware programming.

### What JLCPCB Assembles For You

All surface-mount components on the board:
- PIC16F1713 microcontroller (SOIC-28)
- Output MOSFETs, diodes, inductors
- All resistors, capacitors
- LEDs (SMD)
- Reverse polarity protection
- Fuse
- Connectors (USB-C, JST headers)

### What You Do After Receiving The Board

1. **Flash firmware** via the ICSP header (one-time, ~2 minutes)
2. **Set the boost module** output to ~12V with its trim pot
3. **Plug in** the boost module via JST connector
4. **Plug in** the cup adapter via JST connector
5. **Plug in** USB-C power

No soldering required for normal assembly. The only soldering is attaching wires to the pogo pins inside the 3D-printed cup adapter (two solder joints).

---

## What You Need Before Ordering

### 1. PCB Design Files (Gerbers)

You need Gerber files for the PCB layout. Two options:

**Option A: Use the AN2265 reference layout (recommended starting point)**
- The original Microchip reference design PCB files are in `Nebulizer Reference Design/Board Layout/`
- These need modification to add JST connectors and the boost module header
- If you have KiCad experience, this is a ~2 hour modification

**Option B: Community PCB design**
- If a KiCad project is added to this repo in `hardware/pcb/`, use those Gerber files directly
- Check the repo for updates — a turnkey-optimized PCB layout is planned

### 2. Bill of Materials

Use `docs/BOM_TURNKEY.csv` — it includes JLCPCB-compatible part numbers (LCSC numbers starting with "C").

### 3. Pick-and-Place File (CPL)

This tells JLCPCB where to place each component on the board. It's generated from the PCB design tool (KiCad: Fabrication Outputs > Component Placement).

---

## Step-by-Step JLCPCB Ordering

### Step 1: Upload Gerbers

1. Go to JLCPCB's order page
2. Click **"Add gerber file"**
3. Upload your Gerber ZIP file
4. The system auto-detects board dimensions and layers

### Step 2: Configure PCB Options

Use these settings for best results:

| Setting | Value | Notes |
|---|---|---|
| **Base Material** | FR-4 | Standard, cheapest |
| **Layers** | 2 | Two-layer board is sufficient |
| **Dimensions** | (auto-detected) | ~50x70mm expected |
| **PCB Qty** | 5 | Minimum order. Extra boards = spares |
| **PCB Thickness** | 1.6mm | Standard |
| **PCB Color** | Any | Green is cheapest. Black looks professional. |
| **Surface Finish** | HASL (lead-free) | Good for hand-soldering if needed later |
| **Copper Weight** | 1 oz | Standard |
| **Delivery Format** | Single PCB | Not panelized |

**PCB cost: ~$2-5 for 5 boards**

### Step 3: Enable SMT Assembly

1. Toggle **"PCB Assembly"** on
2. Select:
   - **Assembly Side:** Top (or both if your design has bottom components)
   - **Assembly Qty:** How many boards to assemble (2-5 recommended)
   - **Tooling Holes:** "Added by JLCPCB" (let them add tooling holes automatically)

### Step 4: Upload BOM and CPL

1. Click **"Add BOM File"** — upload the BOM CSV
2. Click **"Add CPL File"** — upload the component placement file
3. JLCPCB will match your BOM parts to their LCSC inventory

### Step 5: Review Part Matching

JLCPCB shows a parts confirmation page. Check each part:

| Your Part | What to Verify |
|---|---|
| PIC16F1713-I/SO | Correct package (SOIC-28), correct part number |
| IRLML0100 | SOT-23, correct MOSFET |
| C7 (4.7nF 200V) | **Critical** — verify this is 4.7 **nano**farads, not microfarads |
| Inductors (150uH) | Verify value and current rating |

**Common issues:**
- If a part shows "No stock", click the part to search for alternatives. For resistors and standard caps, JLCPCB has many equivalent parts.
- The PIC16F1713 may be listed as an "Extended" part (extra $3 setup fee for extended parts, charged once per order).

### Step 6: Review Placement Preview

JLCPCB shows a 3D preview of component placement. Verify:
- IC orientation (pin 1 dot matches)
- Connector positions
- No overlapping parts

### Step 7: Order

1. Add to cart
2. Select shipping (DHL Express is ~$20-30, takes 4-7 business days)
3. Pay

### Cost Summary

| Item | Cost (typical) |
|---|---|
| PCB fabrication (5 boards) | $2-5 |
| SMT assembly (per board) | $8-15 |
| Extended part fee (PIC16F1713) | $3 (one-time) |
| Components (LCSC parts) | $3-8 per board |
| Shipping (DHL) | $20-30 |
| **Total for 5 assembled boards** | **~$50-80** |
| **Per-board cost** | **~$10-16** |

This is remarkably cheap. For context, the Aerogen Pro-X controller costs $2,700.

---

## After You Receive The Boards

### Step 1: Visual Inspection

- Check that all components are present and properly soldered
- Look for solder bridges (especially on the SOIC-28 MCU pins)
- Verify the USB-C connector is seated flat

### Step 2: Flash Firmware

You need the MPLAB Snap (or PICkit 4/5) programmer. This is a one-time purchase (~$35) that works for all future boards.

1. Install MPLAB X IDE and XC8 compiler (both free from Microchip)
2. Open the firmware project from `firmware/`
3. **Edit `firmware/src/config.h`:**
   ```c
   #define BOOST_MODE    BOOST_MODE_MODULE
   ```
4. Connect the MPLAB Snap to the board's ICSP header (5-pin)
5. Click "Make and Program Device" in MPLAB X
6. Programming takes ~10 seconds

### Step 3: Prepare the Boost Module

1. Connect the MT3608/XL6009 module's input to a 5V source (USB charger works)
2. Measure the output with a multimeter
3. Turn the trim pot until output reads **~12V**
4. Disconnect

### Step 4: Assemble

1. **Mount PCB** in enclosure using M2.5 screws (see `hardware/enclosure/`)
2. **Connect boost module** to the JST header labeled "BOOST IN" on the PCB
3. **Connect cup adapter** JST cable to the output header
4. **Snap on enclosure lid**
5. **Slide adapter** onto dovetail dock

### Step 5: First Power-Up Test

1. **Do NOT connect a nebulizer cup yet**
2. Plug in USB-C power
3. Red LED should illuminate (IDLE state)
4. Measure VBOOST on the boost module output — should read ~12V
5. Press the start button — red LED should blink (searching for cup)
6. After ~3 seconds with no cup, it should error (blinking red) — this is correct
7. Fill a cup with **normal saline**, seat it in the adapter
8. Press start — green LED should light when resonance is found
9. Fine mist should appear within seconds

---

## JLCPCB 3D Printing Service

JLCPCB also offers 3D printing. You can order the cup adapter and enclosure at the same time as the PCB.

### Ordering 3D Prints

1. On JLCPCB, go to **"3D Printing"** (top menu)
2. Upload the STL files:
   - `hardware/adapters/aerogen_solo_adapter.stl` (export from OpenSCAD first)
   - `hardware/enclosure/controller_enclosure_base.stl`
   - `hardware/enclosure/controller_enclosure_lid.stl`
3. Select material:
   - **SLA (resin):** Smoother surface, better detail for pogo pin channels. ~$3-8 per part.
   - **MJF (nylon):** More durable, better for the enclosure. ~$5-12 per part.
   - **FDM:** Cheapest but roughest. Fine for the enclosure, marginal for adapter. ~$2-5.
4. For the **cup adapter**, SLA resin is recommended — the pogo pin channels need precision
5. For the **enclosure**, any process works. MJF nylon is most durable.

### Material Recommendations

| Part | Best Material | Why |
|---|---|-----|
| Cup adapter | SLA resin (or PETG if home printing) | Precision for pogo pin fit |
| Enclosure base | MJF nylon or PETG | Durability, chemical resistance |
| Enclosure lid | MJF nylon or PETG | Same as base |

---

## Ordering Checklist

- [ ] Export Gerber files from PCB design (ZIP format)
- [ ] Export BOM in JLCPCB format (CSV with LCSC part numbers)
- [ ] Export CPL/pick-and-place file (CSV)
- [ ] Upload all three to JLCPCB
- [ ] Verify part matching (especially C7 = 4.7nF, PIC16F1713 = SOIC-28)
- [ ] Order PCBs + assembly
- [ ] Order boost module(s) from Amazon/AliExpress
- [ ] Export STL files from OpenSCAD for adapter and enclosure
- [ ] Order 3D prints (JLCPCB, or print at home)
- [ ] Order P75-B1 pogo pins
- [ ] Order JST-XH cables and M2.5 screws
- [ ] Have MPLAB Snap programmer ready
- [ ] Download and install MPLAB X IDE + XC8 compiler

---

## FAQ

**Q: Can JLCPCB pre-program the PIC16F1713 firmware?**
A: No, JLCPCB doesn't offer microcontroller programming. You need the MPLAB Snap (~$35, one-time) to flash the firmware yourself. This takes about 2 minutes per board.

**Q: What if a component is out of stock at LCSC?**
A: For passive components (resistors, caps), JLCPCB will suggest alternatives with identical specs. For the PIC16F1713 or specific MOSFETs, you may need to wait for restock or order those parts separately and solder them yourself (just 1-2 parts).

**Q: Can I order just 1 board?**
A: PCB minimum is 5 boards (but they cost ~$0.50 each). Assembly minimum is typically 2 boards. The marginal cost of assembling all 5 is small — do it and keep spares.

**Q: Can I use PCBWay or OSH Park instead of JLCPCB?**
A: Yes. Any PCB fabricator that offers SMT assembly will work. JLCPCB tends to be the cheapest for small quantities. PCBWay is comparable. OSH Park doesn't offer assembly but makes excellent bare PCBs if you want to solder yourself.

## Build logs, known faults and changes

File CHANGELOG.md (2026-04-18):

# Changelog

All notable changes to this project will be documented in this file.

## [Unreleased]

### Added
- `CONTRIBUTING.md` describing the PR process, code style, and local
  check workflow.
- `SECURITY.md` with a coordinated-disclosure policy for safety bugs.
- `firmware/Makefile` — auto-discovers every source under `firmware/src/`
  so adding a new `.c` no longer requires editing the build command.
- `firmware/tests/` — host-side unit tests for the NCO ↔ Hz config
  macros, the LiPo SOC curve in `peripherals.c`, and the LCD line
  formatters in `lcd.c`. Wired into the existing firmware CI workflow.
- `.pre-commit-config.yaml` running markdownlint, cppcheck, and the
  firmware tests locally on every commit.
- `.github/ISSUE_TEMPLATE/` (bug, feature, cup-compatibility) and
  `.github/pull_request_template.md`, both surfacing the safety review
  checklist.
- `hardware/README.md` documenting where each design file lives and
  how to render the OpenSCAD models.
- `FIRMWARE_VERSION` macro in `config.h` so the splash screen and UART
  banner read from one source of truth.

### Changed
- `firmware/README.md` build instructions now include `lcd.c`/`lcd.h`
  (added in v3.1) and reference the new Makefile.
- `.github/workflows/openscad.yml` now renders **every** `.scad` under
  `hardware/` instead of an explicit list, so new models can't slip
  past CI. `*_config.scad` / `*_common.scad` are skipped as include-only.
- `.gitattributes` now marks binary asset types (`.png`, `.pdf`, `.stl`,
  `.gcode`, `.AppImage`, etc.) explicitly so Git stops trying to
  diff/normalize them, and pins all source files to LF line endings.

### Fixed
- Lid LCD standoffs were touching the lid plate at exactly the same
  z-plane and rendered as four floating volumes — slicers could
  silently drop them. They now overlap the plate by 0.05 mm and fuse
  cleanly (`controller_enclosure_lid.scad`).
- Same fusion fix applied to PCB standoffs, LiPo retaining ribs, and
  TP4056 locating ribs in `controller_enclosure.scad`.
- "VMN" lid label was recessed into the *inner* face of the lid, where
  it can't be seen. Moved it to the outer face so it's visible after
  printing upside-down (`controller_enclosure_lid.scad`).
- Universal adapter "dovetail" was a plain rectangular bar that didn't
  actually dovetail. Now extrudes a true trapezoidal profile via a new
  `dovetail_taper` parameter (`universal_adapter.scad`).

## [3.1] — 2026-04-12 (updated 2026-04-12)

Quality-of-life build for daily nursery use: rechargeable cell, USB-C
charging, and a status display.

### Added
- 1S LiPo pouch cell (103450, ~2000 mAh) powering MCU + boost module
  directly (3.0-4.2 V rail)
- TP4056 + DW01A USB-C charging module with over-charge, over-discharge
  and short-circuit protection
- 16x2 character display driver (`firmware/src/lcd.c`) with bit-bang
  I2C over RC4/RC5 and auto-probing PCF8574 backpack address
- `LCD_IS_OLED` config flag — same driver handles cheap HD44780 LCDs
  (~$3) and premium character OLEDs like Winstar WEH001602, Newhaven
  NHD-0216AW, and Matrix Orbital MOP-AO162 (~$25)
- Battery monitoring via the PIC's Fixed Voltage Reference — reads VDD
  with zero external parts (`peripherals.c::battery_read_mv`)
- Piecewise-linear LiPo state-of-charge curve
- Soft battery cutoff at 3.1 V — warns the user and auto-stops any
  running treatment before the DW01A hardware cutoff trips
- Splash screen showing firmware version on power-up
- Status line showing state + resonant frequency, and battery percent +
  elapsed time while running
- `enclosure_config.scad` — shared dimensions used by both base and
  lid SCAD files
- `controller_enclosure_lid.scad` — separate lid file with a 16x2
  viewing window, four M3 standoffs and a wire-pass slot
- LiPo + TP4056 bay in the enclosure base with USB-C aperture on the
  front wall and an internal shelf that stacks the TP4056 above the
  pouch cell
- New BOM rows and cost estimates for the LiPo, TP4056, and display
  options (~$30-45 with LCD, ~$45-70 with character OLED)

### Changed
- `controller_enclosure.scad` now renders only the base and `include`s
  the shared config file. PCB component clearance bumped from 12 mm to
  18 mm so the LCD backpack has room to hang down from the lid.
- PCB USB-C receptacle replaced with a JST-PH BAT IN header — the
  USB-C port now lives on the TP4056 module
- RC4/RC5 reassigned from "unused" to software I2C for the display
- Firmware banner bumped to v3.1
- Build guide rewritten with new steps for LiPo bay prep, display
  mounting, and a first power-up sequence that includes the splash
  and status screens

### Changed (post-audit)
- Device named **Nimbus Nebulizer Controller**. LCD splash, UART banner,
  README title, and build guide updated. Filenames and branch unchanged.
- `LCD_IS_OLED` now defaults to `1` (character OLED). Character OLEDs
  operate down to 3.0 V, matching the full LiPo discharge range. The cheap
  HD44780 LCD remains supported via `LCD_IS_OLED = 0`.

### Fixed
- ICSP cutout Y-coordinate bug in `controller_enclosure.scad` that
  mixed X and Y values
- **Elapsed-time drift** — `TICKS_PER_SEC=8` made the display 4.8% fast
  (30 min session showed 30:00 at only 28:34 elapsed; TIMED mode ended
  86 s early). Replaced with `TIMER1_MS_PER_TICK=131` integer arithmetic
  for < 0.1% error.
- **Boost voltage diagnostic** — in `BOOST_MODE_MODULE`, a failed
  frequency sweep now reads the AN3 boost-feedback ADC. If the reading
  is below `BOOST_VFDBK_MIN_ADC` (default 50 counts), the UART prints
  `ERROR: Vboost too low — check module` and the display shows
  `ERR Vboost low / Check boost mod` instead of the generic `ERR no cup`.
- **Battery sag false-trip** — a single below-threshold battery sample
  during a high-load draw could latch `batt_critical_latched` and abort
  the treatment prematurely. Now requires two consecutive sub-`BATTERY_CRIT_MV`
  readings before the flag latches.
- **`BATTERY_ENABLED=0` display** — `lcd_show_battery(0, 0, 0xFFFF)` was
  called unconditionally, showing "Bat 0% 0.00V" in headless builds. Line 2
  is now left unchanged when battery monitoring is disabled.

## [3.0] — 2026-04-12

Consolidated to a single turnkey build path. No more choosing between build tiers.

### Added
- JLCPCB pre-assembled PCB option (~$15-25/board)
- 3D-printable controller enclosure with battery compartment
- 3D-printable Aerogen Solo connector plug (pogo pin contact)
- Universal adapter template for other VMN cup brands
- Dry-cup auto-stop detection (shuts down when cup is empty)
- Frequency caching to flash (near-instant startup with same cup)
- Smart narrow re-sweep for resonance drift (~150ms vs 2.4s full sweep)
- JLCPCB ordering guide with step-by-step walkthrough
- Mermaid state machine, block, and signal flow diagrams
- Build quality and nursery durability guide
- GitHub Actions CI (static analysis, docs linting, OpenSCAD validation)

### Changed
- Default treatment mode changed from TIMED to CONTINUOUS
- Default treatment time increased from 600s to 1800s
- Boost mode defaults to MODULE (pre-built MT3608) instead of DISCRETE
- Firmware version string updated to v3.0

## [2.0] — 2026-02-15

Simplified controller with continuous treatment support.

### Added
- Continuous treatment mode for long nebulization sessions
- Boost module option (eliminates discrete boost components)
- UART debug output (optional, via MCP2221)

### Changed
- Simplified from three build tiers to two (breadboard + PCB)
- Reduced component count by ~40% with boost module option

## [1.0] — 2026-01-20

Initial release — complete breadboard build from scratch.

### Added
- Full frequency sweep algorithm (90-150 kHz)
- PIC16F1713 firmware with state machine (idle, sweep, run, error)
- Discrete boost converter with DAC-controlled feedback
- Timed treatment mode (10-minute default)
- Complete wiring guide and BOM
- Based on Microchip AN2265 reference design

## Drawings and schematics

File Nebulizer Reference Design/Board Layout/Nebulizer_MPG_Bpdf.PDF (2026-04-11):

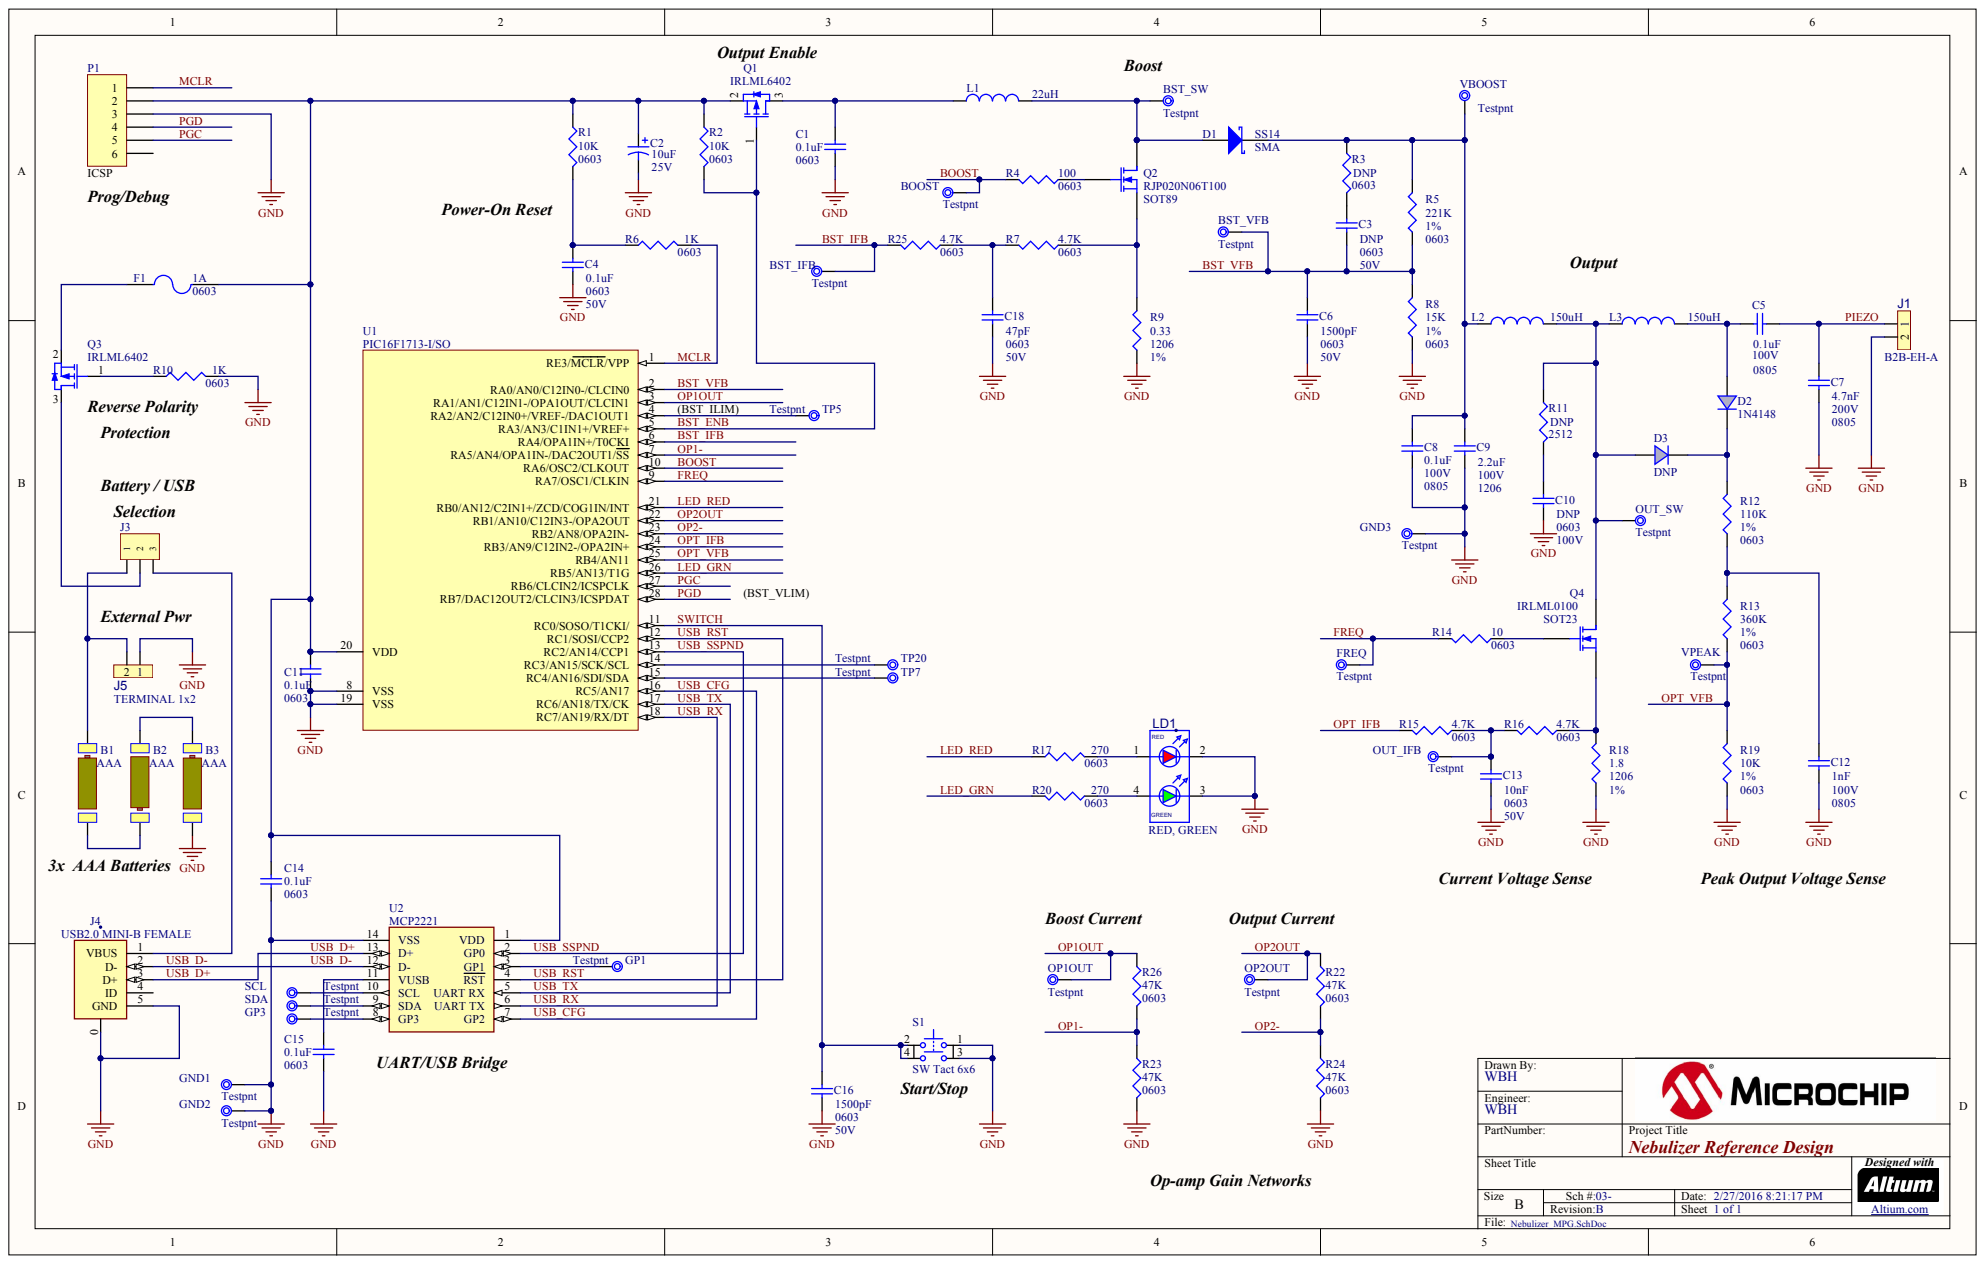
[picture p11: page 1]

C4 5 0 V | 0 6 0 3 MCLR

Reverse Polarity Protection Selection 123

1 | USB_RX

Peak Output Voltage Sense

PartNumber: | Project Title
Nebulizer Reference Design 2/27/2016 8:21:17 PM Sheet Title | Designed with Altium.co m

Op-amp Gain Networks

Size B | Sch # : 0 3 - | Date:

Revisio n : B | Sheet 1 of 1

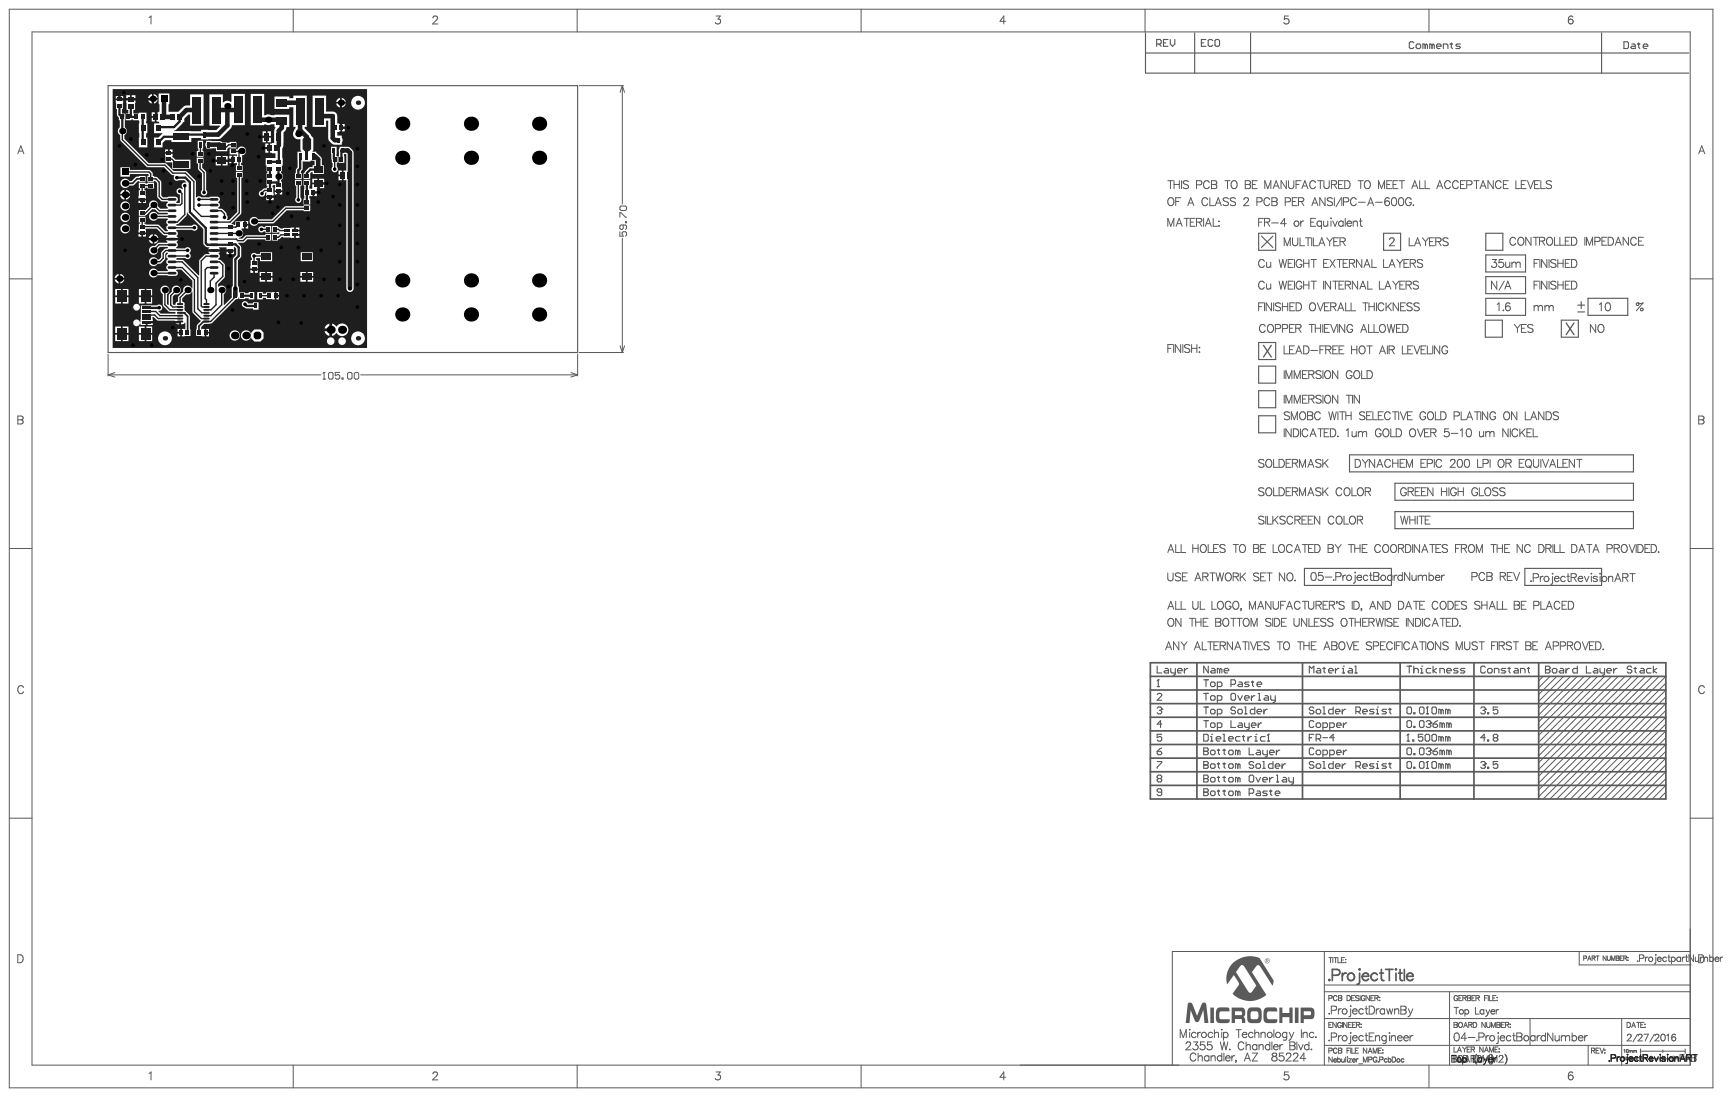
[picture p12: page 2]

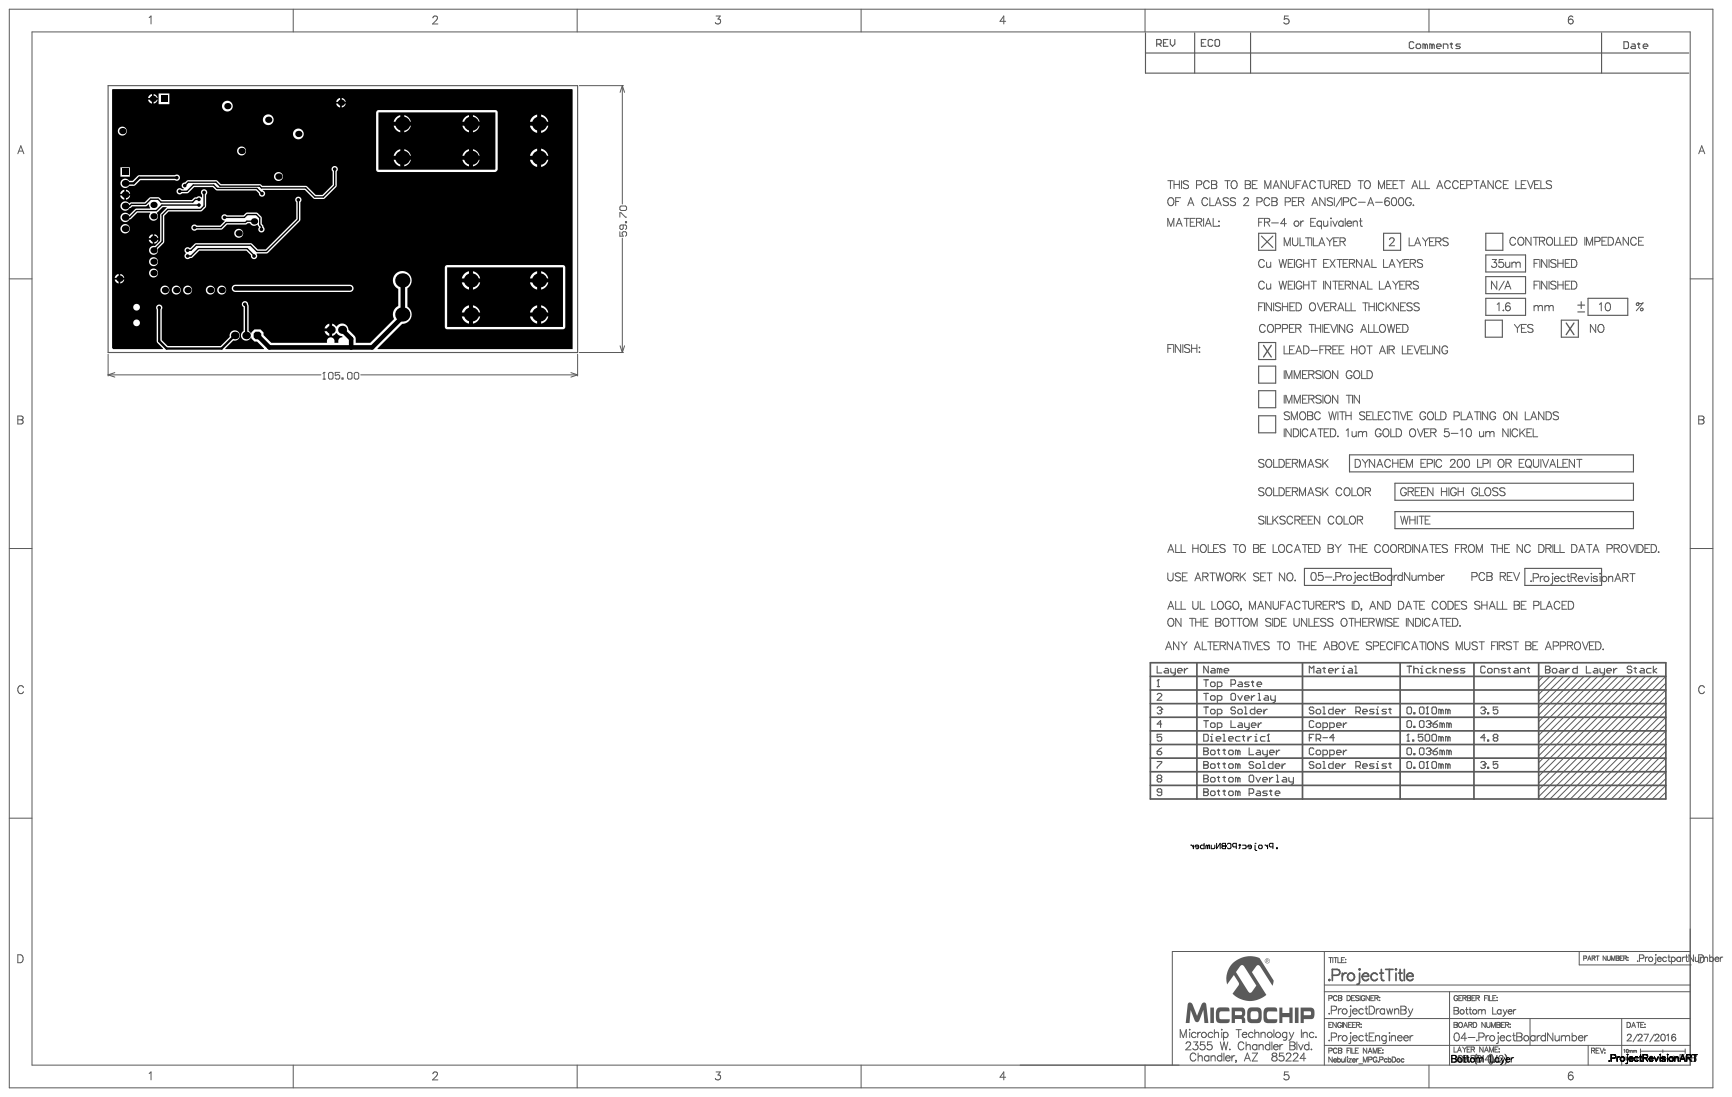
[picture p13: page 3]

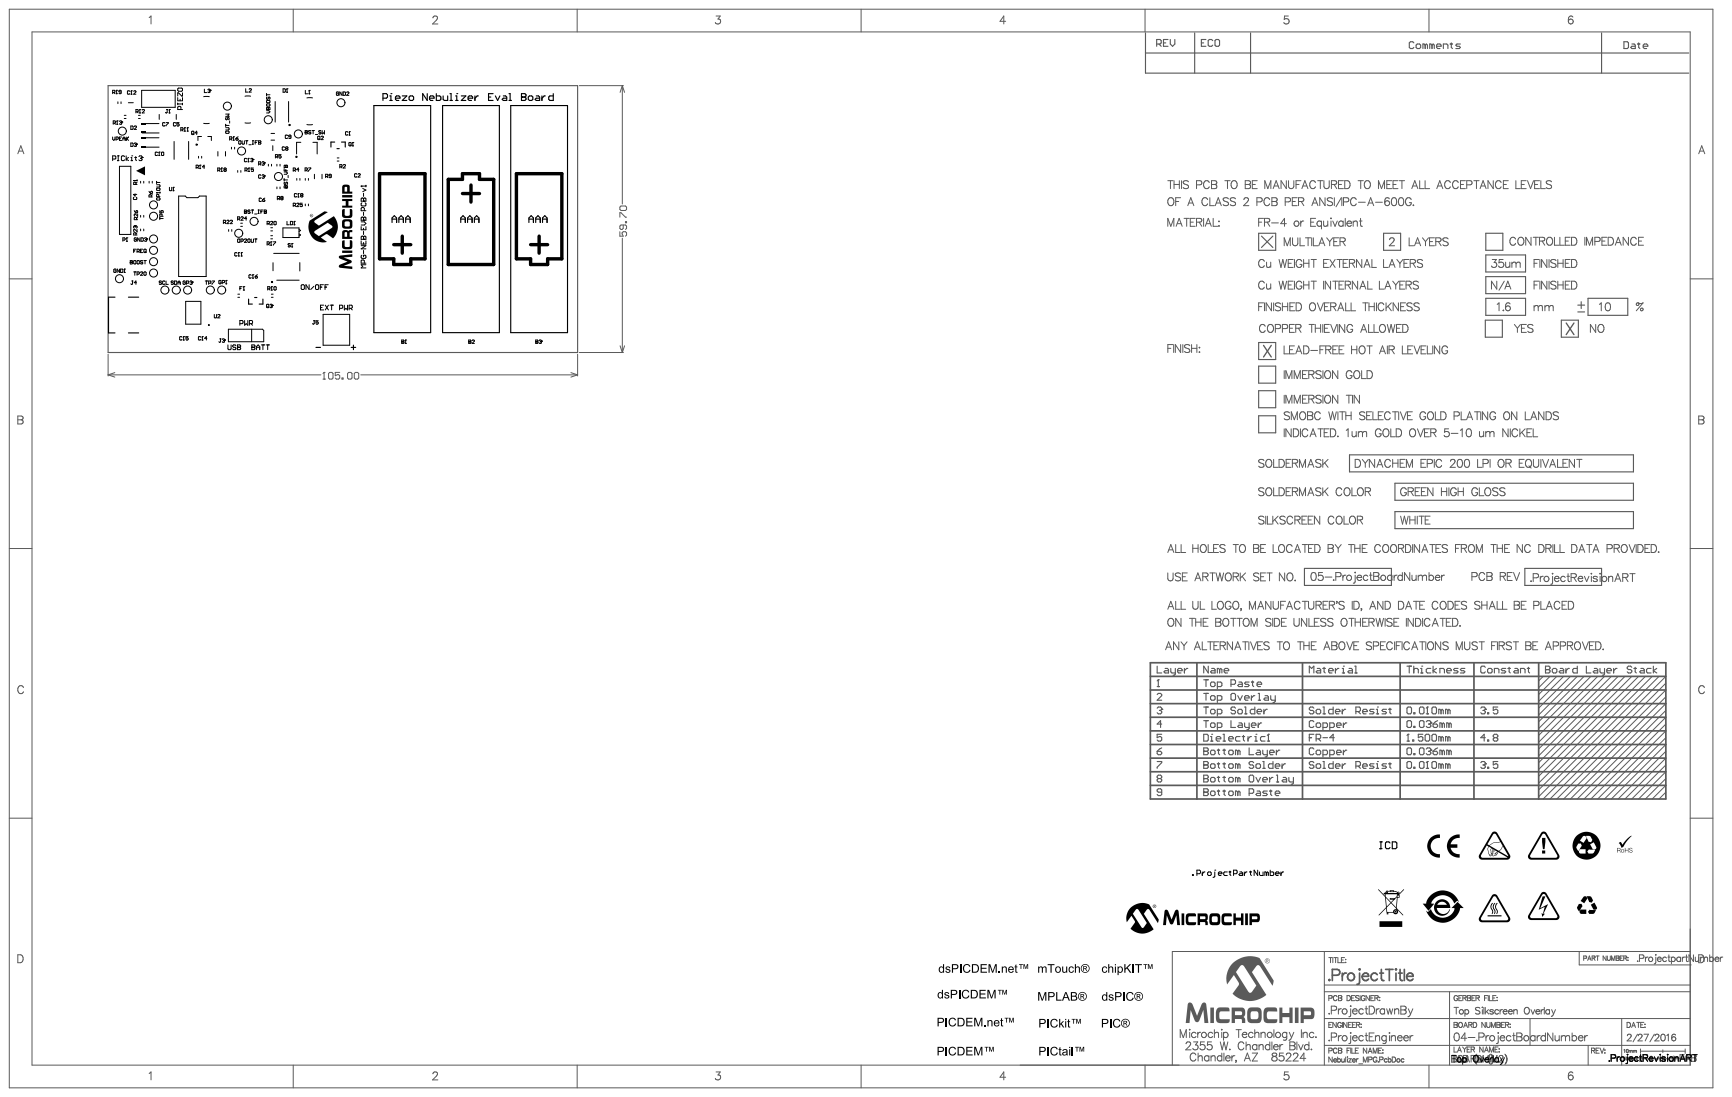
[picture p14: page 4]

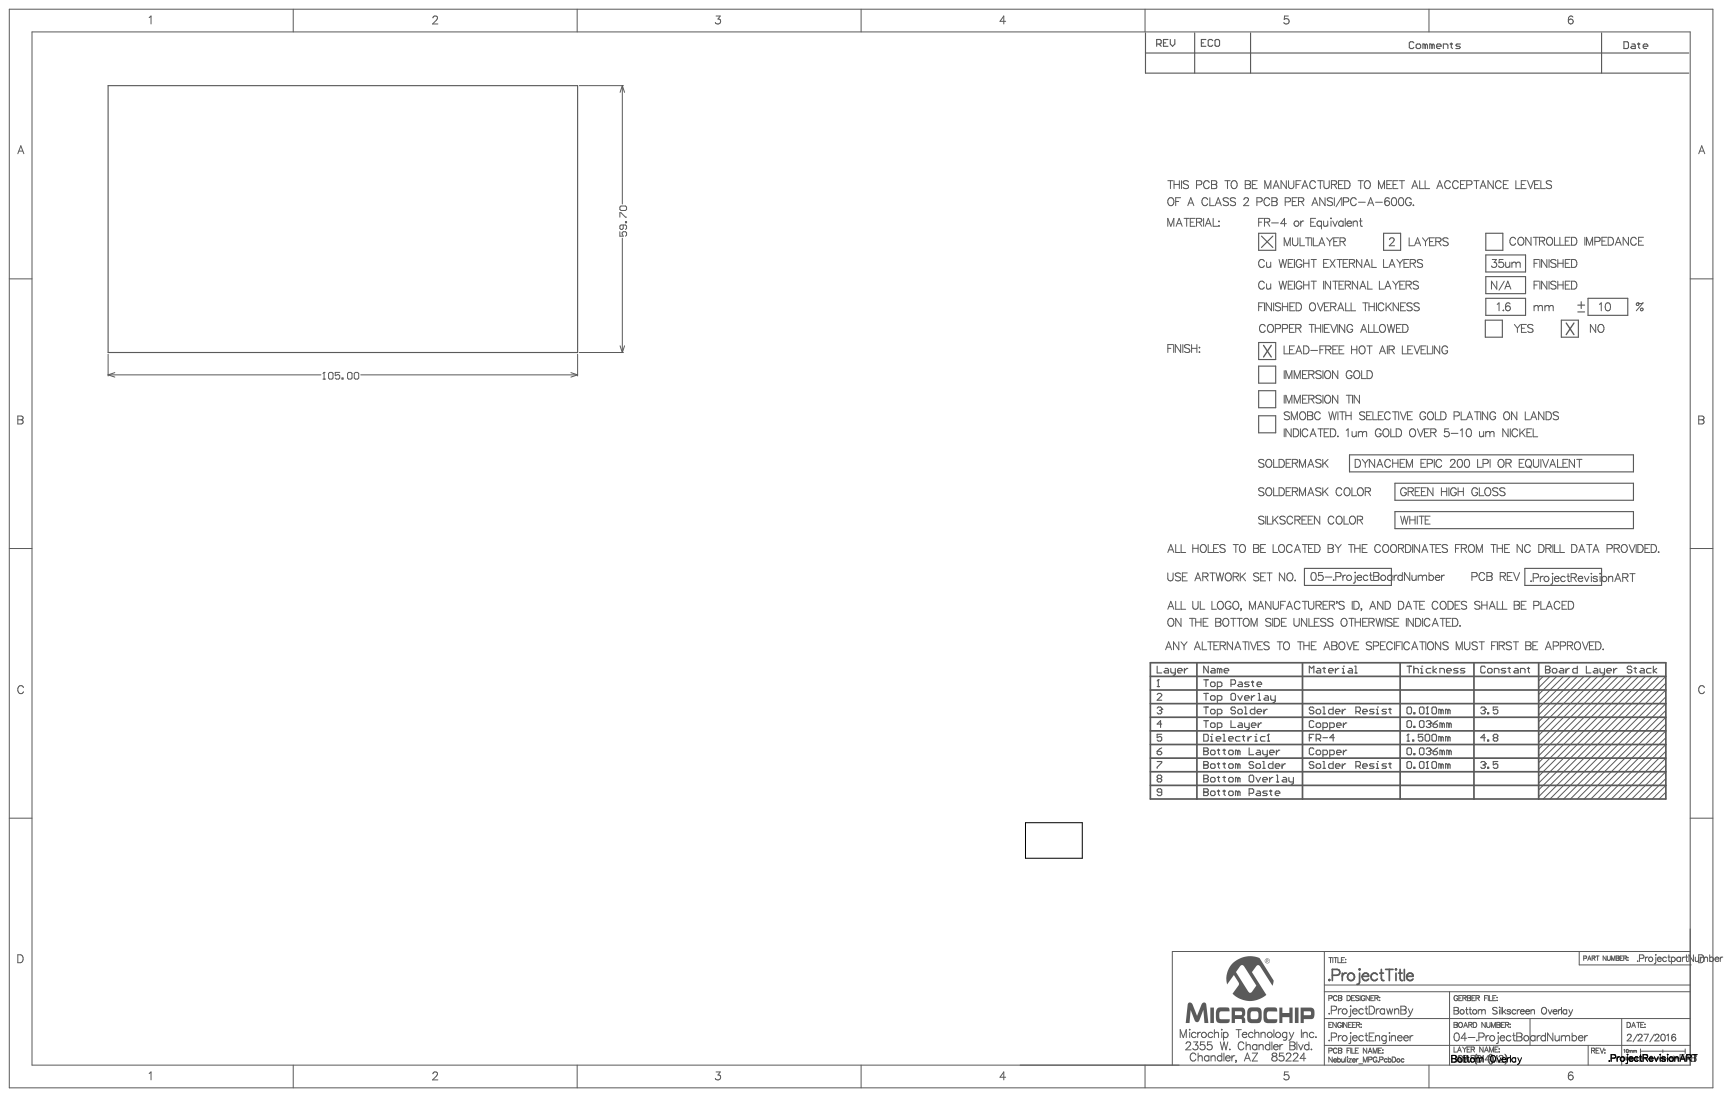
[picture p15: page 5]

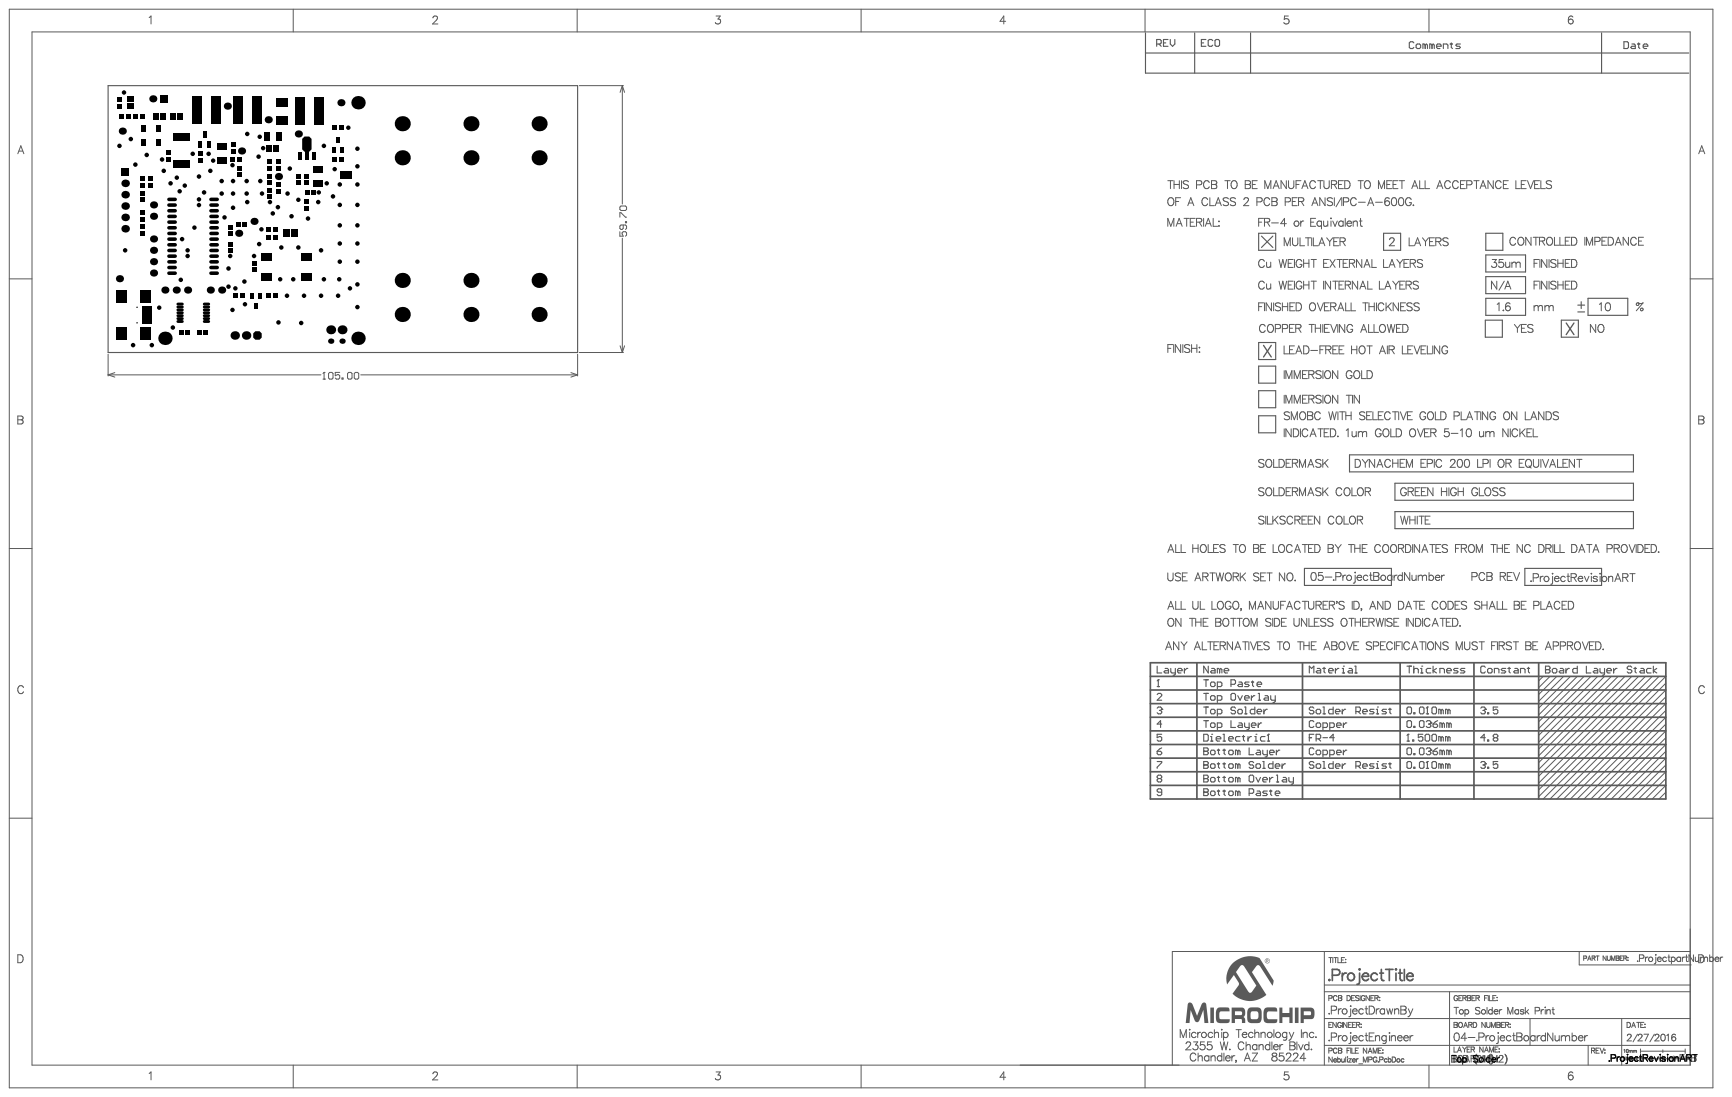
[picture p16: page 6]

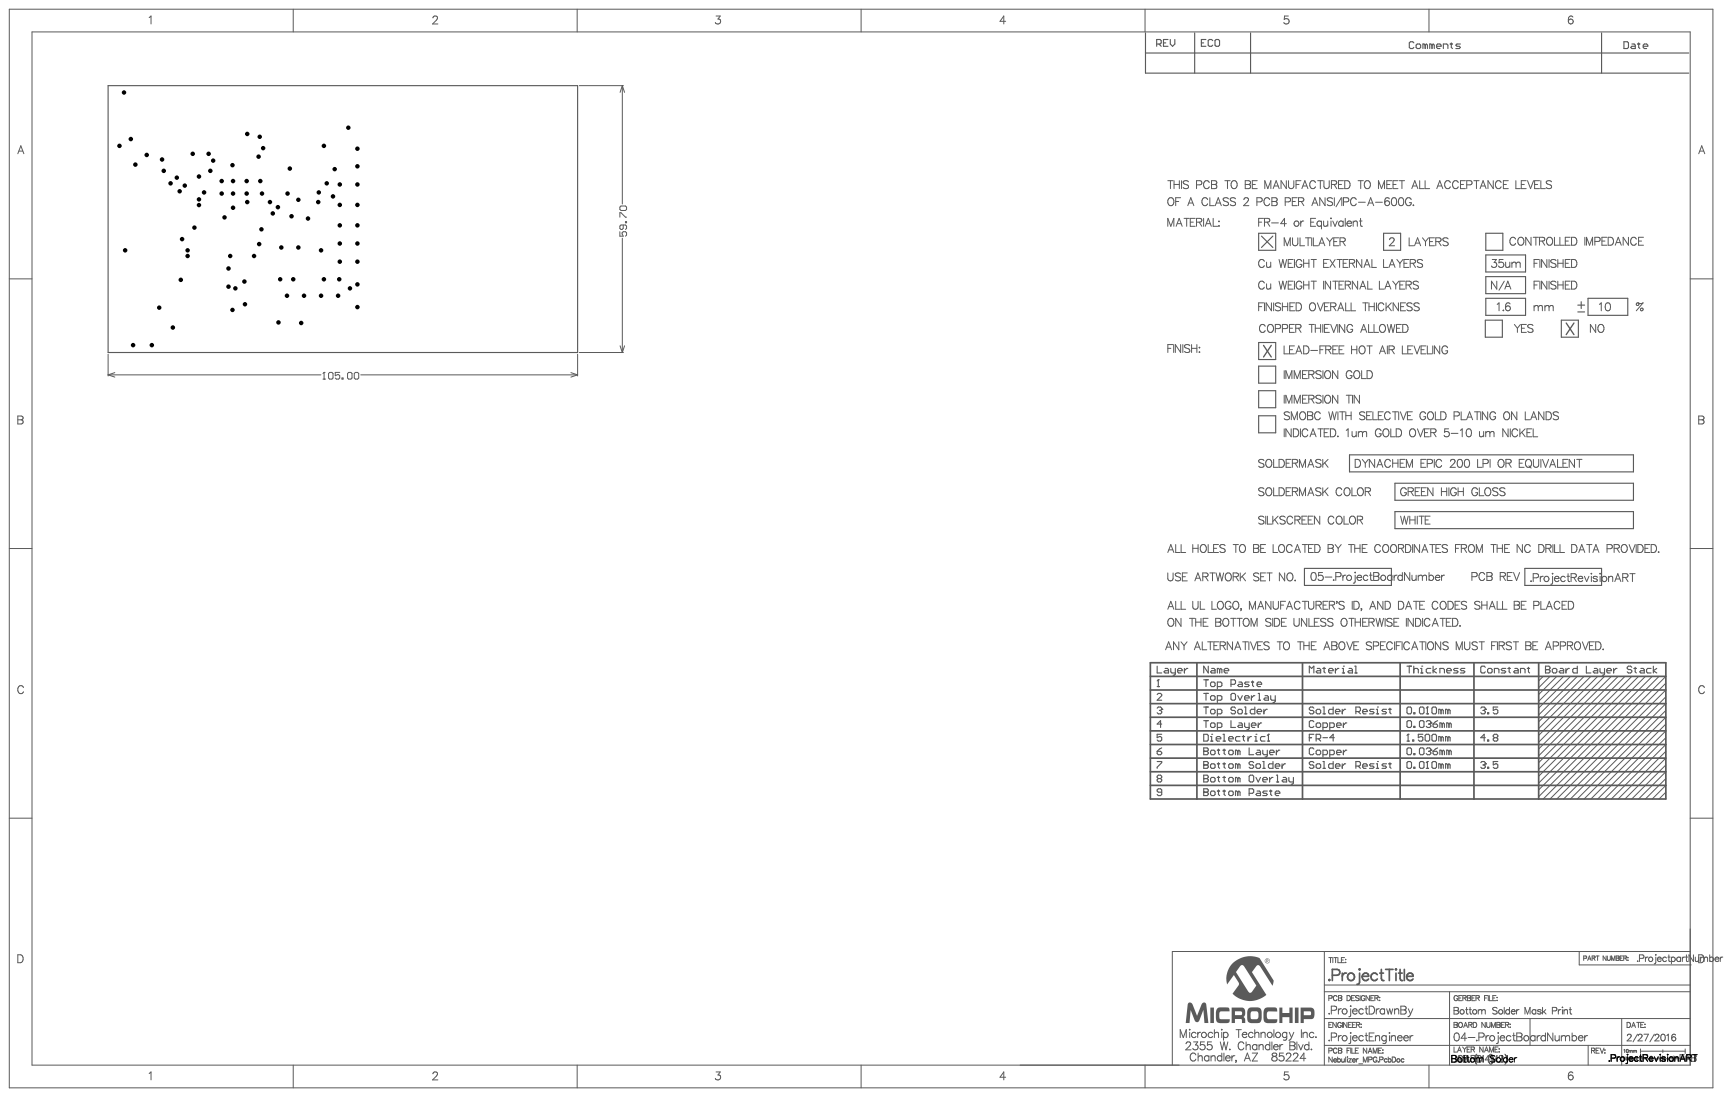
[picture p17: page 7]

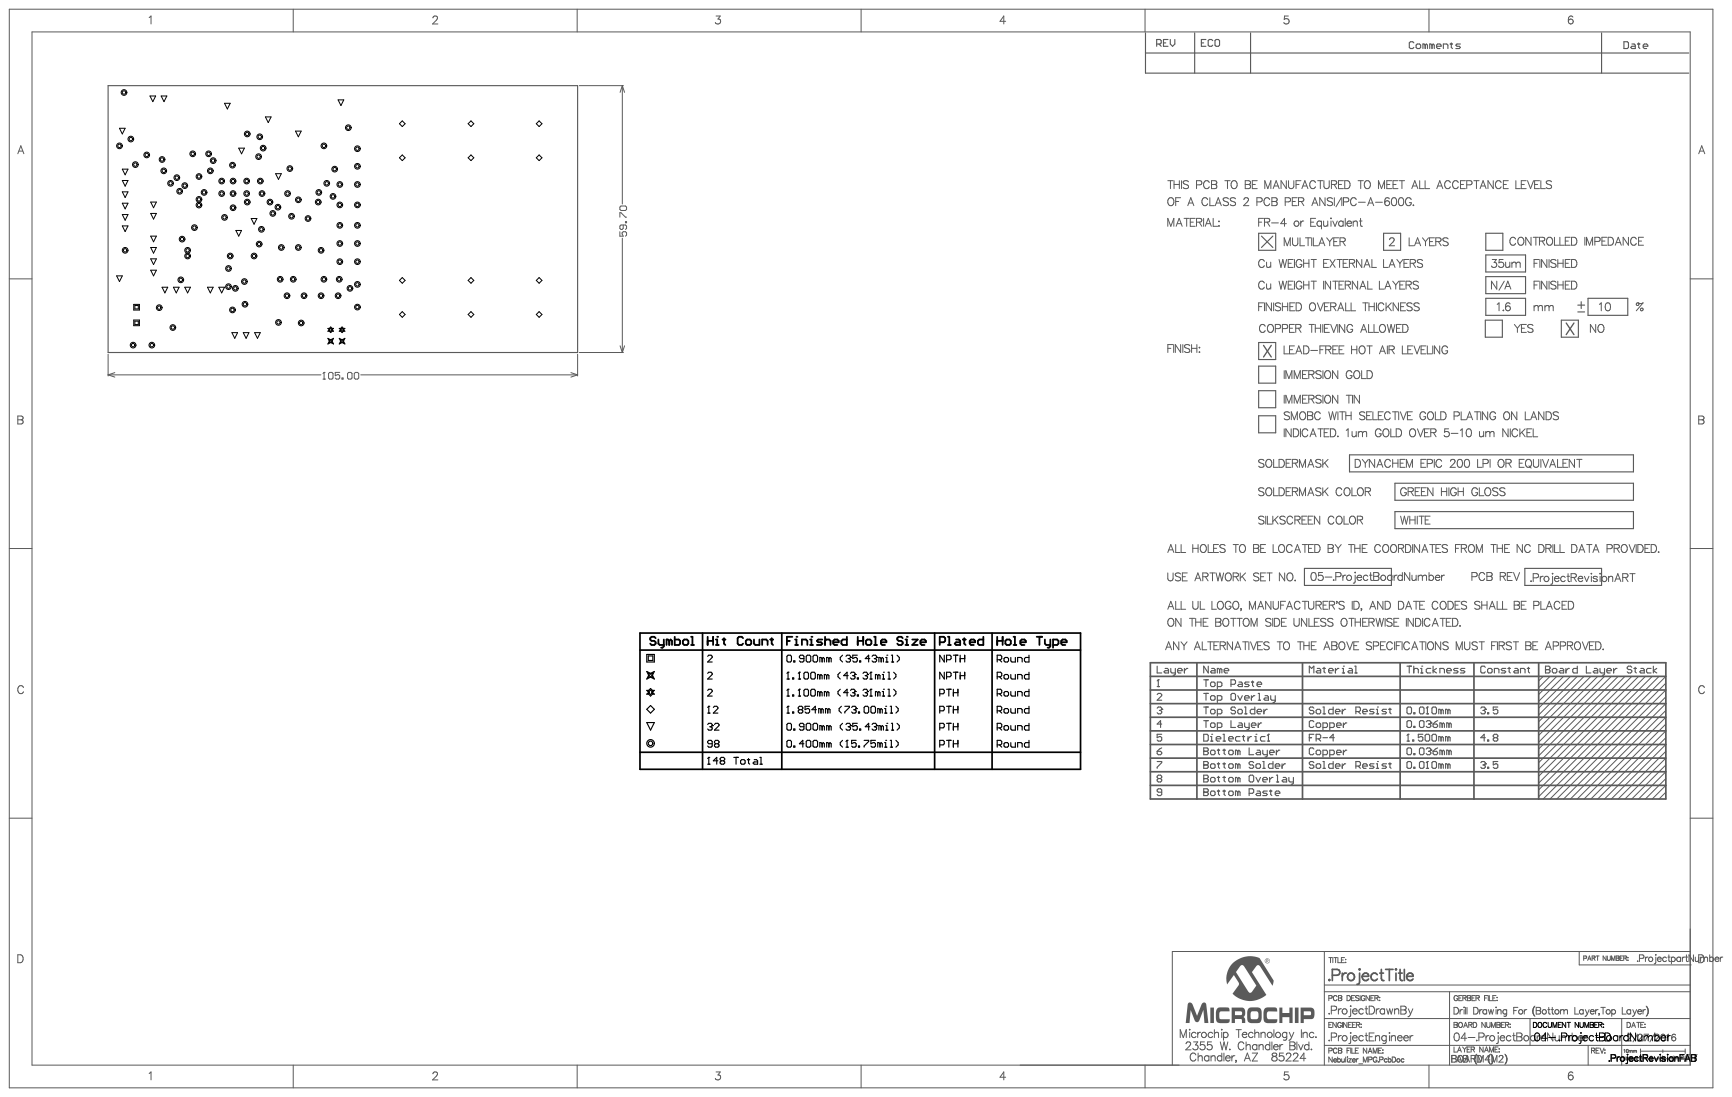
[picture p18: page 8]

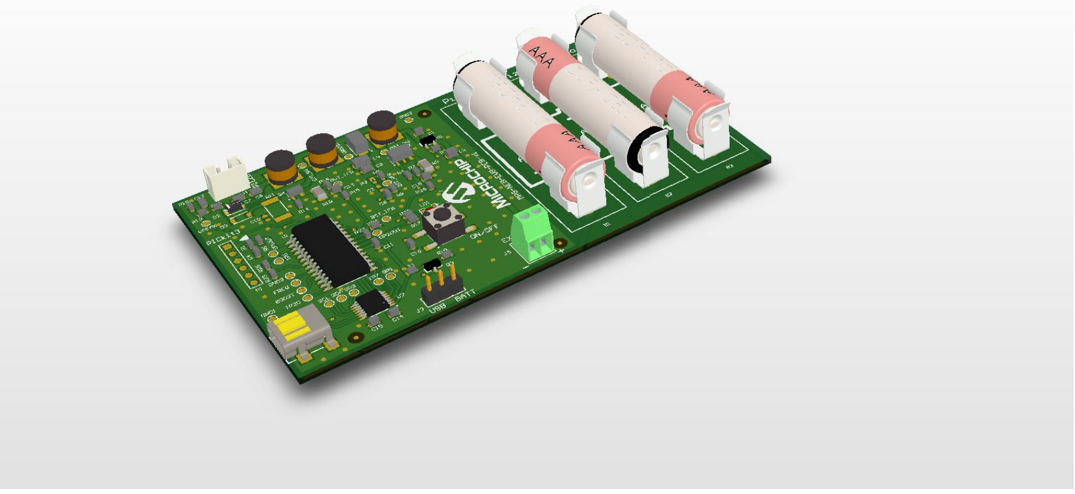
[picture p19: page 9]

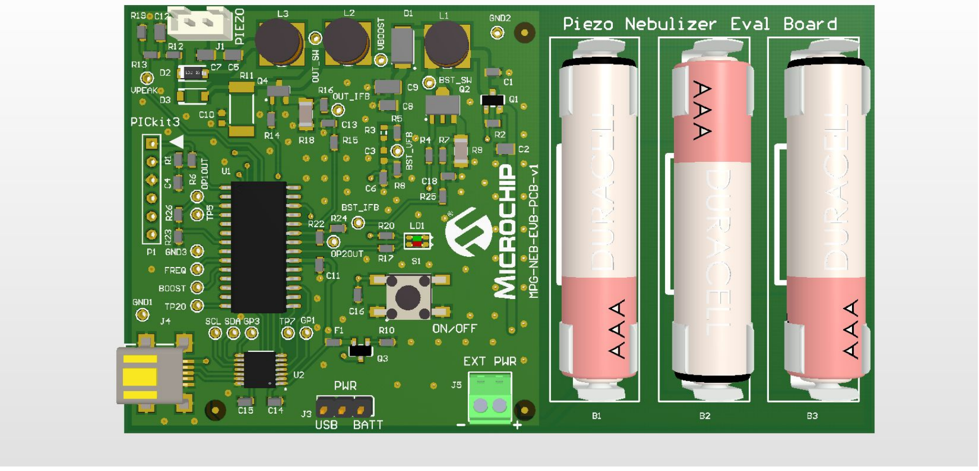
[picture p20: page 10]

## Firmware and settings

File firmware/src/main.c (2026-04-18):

/*
 * main.c — Nimbus Nebulizer Controller
 *
 * Firmware for PIC16F1713 to drive a PZT-based vibrating mesh nebulizer
 * (e.g., Aerogen Solo) via frequency sweep and resonance lock.
 *
 * State machine:
 *   IDLE     — waiting for button press, LEDs indicate ready
 *   SWEEP    — scanning for PZT resonant frequency
 *   RUNNING  — driving PZT at resonance, treatment active
 *   ERROR    — no resonance found or fault detected
 *
 * Key features:
 *   - Continuous treatment mode for long nebulization sessions (100+ mL/day)
 *   - Dry-cup auto-stop: detects empty cup and shuts down safely
 *   - Narrow re-sweep: fast resonance re-acquisition when frequency drifts
 *   - Frequency caching: saves last resonance to flash for fast startup
 *   - Boost module support: simplified build with pre-built boost converter
 *
 * Based on Microchip AN2265 reference design.
 * Target: PIC16F1713-I/SP (DIP-28) on breadboard.
 * Compiler: Microchip XC8 (free mode).
 *
 * IMPORTANT: This is not an FDA-approved medical device.
 * See DISCLAIMER.md for safety information.
 */

#include <xc.h>
#include <stdint.h>
#include "config.h"
#include "peripherals.h"
#include "sweep.h"
#include "lcd.h"

/* ========================================================================
 * State machine
 * ======================================================================== */
typedef enum {
    STATE_IDLE,
#if BOOST_MODE == BOOST_MODE_DISCRETE
    STATE_BOOST_RAMP,
#endif
    STATE_SWEEP,
    STATE_RUNNING,
    STATE_STOPPING,
    STATE_ERROR
} state_t;

static state_t          state;
static sweep_result_t   resonance;
static uint16_t         treatment_ticks;     /* Timer1 overflow counter */
static uint16_t         treatment_max_ticks; /* Ticks for full treatment duration */
static uint16_t         recheck_ticks;       /* Ticks since last resonance recheck */
static uint16_t         recheck_max_ticks;   /* Ticks per recheck interval */
static uint16_t         dry_cup_ticks;       /* Ticks of sustained low current */
static uint16_t         dry_cup_max_ticks;   /* Ticks for dry-cup confirmation */
#if BOOST_MODE == BOOST_MODE_DISCRETE
static uint8_t          current_dac;         /* Current boost DAC level */
#endif
#if FREQ_CACHE_ENABLED
static uint16_t         cached_freq;         /* Loaded from HEF on startup */
#endif

#if BATTERY_ENABLED
static uint16_t         batt_mv;             /* Most recent battery reading (mV) */
static uint8_t          batt_pct;            /* Most recent SOC estimate (%) */
static uint16_t         batt_sample_cooldown_ms; /* Countdown until next sample */
static uint8_t          batt_critical_latched;   /* 1 once battery has dropped below CRIT */
static uint8_t          batt_crit_consec;        /* Consecutive sub-CRIT samples (need ≥2) */
#endif

#if LCD_ENABLED
static uint16_t         lcd_refresh_cooldown_ms; /* Countdown until next refresh */
static uint8_t          lcd_present;             /* 1 if LCD was detected at boot */
#endif

#if BOOST_MODE == BOOST_MODE_MODULE
static uint8_t          error_boost_low;     /* 1 if last sweep failed due to low Vboost */
#endif

/* Return a short label for the current state, suitable for the LCD. */
#if LCD_ENABLED
static const char *state_label(state_t s)
{
    switch (s) {
        case STATE_IDLE:       return "READY";
#if BOOST_MODE == BOOST_MODE_DISCRETE
        case STATE_BOOST_RAMP: return "RAMP";
#endif
        case STATE_SWEEP:      return "SWEEP";
        case STATE_RUNNING:    return "RUN";
        case STATE_STOPPING:   return "STOP";
        case STATE_ERROR:      return "ERR";
        default:               return "?";
    }
}
#endif

/*
 * Timer1 overflow period: 131.072 ms exactly (65536 counts × 8 prescaler / 4 MHz).
 * True ticks per second: 1000 / 131.072 ≈ 7.630.
 *
 * The previous TICKS_PER_SEC=8 approximation made the elapsed-time display
 * ~4.8% fast — a 30-min treatment showed 30:00 on the LCD when only ~28:34
 * had actually passed, and TIMED mode ended ~86 s early.
 *
 * Use 131 ms/tick for all integer arithmetic (rounds down by 0.054 %,
 * well inside the 500 ms LCD refresh granularity):
 *   elapsed_sec  = ticks × 131 / 1000
 *   ticks needed = time_sec × 1000 / 131
 */
#define TIMER1_MS_PER_TICK  131UL       /* Nominal ms per Timer1 overflow */
#define MS_TO_TICKS(ms)     ((uint16_t)((uint16_t)(ms) / TIMER1_MS_PER_TICK + 1))
#define LOOP_PERIOD_MS      10          /* Main loop cadence — 1 iteration = 10 ms */
#define TICKS_TO_SEC(t)     ((uint16_t)((uint32_t)(t) * TIMER1_MS_PER_TICK / 1000UL))

/* ========================================================================
 * Button debounce
 *
 * Simple polling debounce. Returns 1 on a clean button press (transition
 * from not-pressed to pressed, held for >50ms).
 * ======================================================================== */
static uint8_t button_debounced(void)
{
    static uint8_t last_state = 0;
    static uint8_t debounce_count = 0;
    uint8_t current = button_pressed();

    if (current && !last_state) {
        debounce_count++;
        if (debounce_count >= 5) {  /* 5 polls ≈ 50ms in main loop */
            last_state = 1;
            debounce_count = 0;
            return 1;               /* Button press detected */
        }
    } else if (!current) {
        last_state = 0;
        debounce_count = 0;
    }

    return 0;
}

/* ========================================================================
 * Boost voltage ramp (discrete boost only)
 *
 * Gradually increases the DAC from BOOST_STARTUP_DAC to BOOST_TARGET_DAC.
 * This prevents inrush current and gives the boost converter time to
 * stabilize at each voltage step.
 * ======================================================================== */
#if BOOST_MODE == BOOST_MODE_DISCRETE
static uint8_t boost_ramp_step(void)
{
    if (current_dac < BOOST_TARGET_DAC) {
        current_dac++;
        dac_set_value(current_dac);
        return 0;   /* Still ramping */
    }
    return 1;       /* Ramp complete */
}
#endif

/* ========================================================================
 * LED patterns for each state
 * ======================================================================== */
static void update_leds(void)
{
    switch (state) {
        case STATE_IDLE:
            led_red_on();       /* Solid red = powered, idle */
            led_green_off();
            break;

#if BOOST_MODE == BOOST_MODE_DISCRETE
        case STATE_BOOST_RAMP:
            led_red_on();
            led_green_off();    /* Red = ramping boost voltage */
            break;
#endif

        case STATE_SWEEP:
            led_red_off();      /* Green blinks during sweep (toggled in sweep.c) */
            break;

        case STATE_RUNNING:
            led_red_off();
            led_green_on();     /* Solid green = nebulizing */
            break;

        case STATE_STOPPING:
            led_red_off();
            led_green_off();    /* Both off briefly during shutdown */
            break;

        case STATE_ERROR:
            /* Blink red for error — toggled in main loop */
            led_green_off();
            break;
    }
}

/* ========================================================================
 * Battery sampling — call each loop iteration. Updates batt_mv/batt_pct
 * on a BATTERY_SAMPLE_MS cadence and latches a critical flag when the
 * cell sags below BATTERY_CRIT_MV so we can stop cleanly.
 * ======================================================================== */
#if BATTERY_ENABLED
static void battery_sample_step(void)
{
    if (batt_sample_cooldown_ms > LOOP_PERIOD_MS) {
        batt_sample_cooldown_ms -= LOOP_PERIOD_MS;
        return;
    }
    batt_sample_cooldown_ms = BATTERY_SAMPLE_MS;

    uint16_t mv = battery_read_mv();
    if (mv == 0) return;             /* Bad reading — keep previous value */

    batt_mv  = mv;
    batt_pct = battery_percent(mv);

    /* Require two consecutive sub-CRIT readings before latching.
     * A single sample can sag 100-200 mV under heavy load and recover
     * immediately at idle — latching on a single glitch would stop a
     * treatment on a cell that still has plenty of charge. */
    if (mv < BATTERY_CRIT_MV) {
        if (++batt_crit_consec >= 2)
            batt_critical_latched = 1;
    } else {
        batt_crit_consec = 0;
    }
}
#endif

/* ========================================================================
 * LCD refresh — cheaply rewrites the two-line display each LCD_UPDATE_MS.
 * Line 1 shows the state + frequency, line 2 shows battery and either
 * elapsed treatment time (while running) or the cell voltage (otherwise).
 * ======================================================================== */
#if LCD_ENABLED
static void lcd_refresh_step(void)
{
    if (!lcd_present) return;

    if (lcd_refresh_cooldown_ms > LOOP_PERIOD_MS) {
        lcd_refresh_cooldown_ms -= LOOP_PERIOD_MS;
        return;
    }
    lcd_refresh_cooldown_ms = LCD_UPDATE_MS;

#if BOOST_MODE == BOOST_MODE_MODULE
    /* Dedicated Vboost error screen overrides the normal status display */
    if (state == STATE_ERROR && error_boost_low) {
        lcd_show_message("ERR Vboost low  ", "Check boost mod ");
        return;
    }
#endif

    /* Pick the right frequency value to show. While running we know the
     * locked resonance; in any other state we show the last cached freq
     * (from HEF) if we have one, otherwise zero. */
    uint32_t freq_hz = 0;
#if FREQ_CACHE_ENABLED
    uint16_t inc_for_display = (state == STATE_RUNNING) ? resonance.peak_inc : cached_freq;
#else
    uint16_t inc_for_display = (state == STATE_RUNNING) ? resonance.peak_inc : 0;
#endif
    if (inc_for_display != 0)
        freq_hz = NCO_INC_TO_HZ(inc_for_display);

    lcd_show_status(state_label(state), freq_hz);

    /* Line 2: battery + elapsed time (if running) or voltage (otherwise). */
#if BATTERY_ENABLED
    uint16_t elapsed = (state == STATE_RUNNING) ? TICKS_TO_SEC(treatment_ticks) : 0xFFFF;
    lcd_show_battery(batt_pct, batt_mv, elapsed);
#endif
    /* No line-2 update when BATTERY_ENABLED=0 — avoids "Bat 0% 0.00V" */
}
#endif

/* ========================================================================
 * Stop nebulization — safe shutdown
 * ======================================================================== */
static void stop_nebulization(void)
{
    nco_disable();
    dac_set_value(0);
#if BOOST_MODE == BOOST_MODE_DISCRETE
    current_dac = 0;
#endif
    timer1_stop();

    led_red_off();
    led_green_off();

    uart_send_string("STOP: nebulization ended\r\n");

    state = STATE_IDLE;
}

/* ========================================================================
 * Start sweep — attempt to find resonance
 *
 * Tries the most efficient approach first:
 *   1. If we have a cached frequency, try a narrow sweep around it
 *   2. If that fails, do a full sweep
 * ======================================================================== */
static void start_sweep(void)
{
#if FREQ_CACHE_ENABLED
    /* Try cached frequency with a narrow sweep first */
    if (cached_freq != 0) {
        uart_send_string("STARTUP: trying cached frequency\r\n");
        resonance = sweep_narrow(cached_freq);

        if (resonance.found) {
            uart_send_string("STARTUP: cached freq still good\r\n");
            return;
        }
        /* Narrow sweep failed — fall through to full sweep */
        uart_send_string("STARTUP: cached freq stale, full sweep\r\n");
    }
#endif

    /* Full sweep */
    resonance = sweep_find_resonance();
}

/* ========================================================================
 * Main
 * ======================================================================== */
void main(void)
{
    uint8_t error_blink_count = 0;

    /* Initialize all peripherals */
    system_init();

    /* Calculate timer tick counts */
    treatment_max_ticks = (uint16_t)((uint32_t)TREATMENT_TIME_SEC * 1000UL / TIMER1_MS_PER_TICK);
    recheck_max_ticks   = MS_TO_TICKS(RECHECK_INTERVAL_MS);
    dry_cup_max_ticks   = MS_TO_TICKS(DRY_CUP_CONFIRM_MS);

    /* Load cached resonant frequency from flash */
#if FREQ_CACHE_ENABLED
    cached_freq = sweep_load_cached_freq();
#endif

    /* Start in idle state */
    state = STATE_IDLE;
#if BOOST_MODE == BOOST_MODE_DISCRETE
    current_dac = 0;
#endif

#if BATTERY_ENABLED
    /* Take a first battery reading before showing the splash so the LCD
     * can display it immediately. */
    batt_mv = battery_read_mv();
    batt_pct = battery_percent(batt_mv);
    batt_sample_cooldown_ms = BATTERY_SAMPLE_MS;
    batt_critical_latched = 0;
    batt_crit_consec = 0;
#endif

#if LCD_ENABLED
    /* Bring up the character LCD. This silently does nothing if no
     * backpack ACKs on the bus (lcd_present stays 0). */
    lcd_present = lcd_init();
    if (lcd_present) {
        lcd_show_message("Nimbus Nebulizer",
                         " Controller " FIRMWARE_VERSION);
    }
    lcd_refresh_cooldown_ms = 1500;   /* Hold the splash ~1.5 s */
#endif

    /* Startup indication: blink red LED once */
    led_red_on();
    delay_ms(500);
    led_red_off();
    delay_ms(250);

    uart_send_string("\r\n=== Nimbus Nebulizer Controller " FIRMWARE_VERSION " ===\r\n");
#if BATTERY_ENABLED
    uart_send_string("Battery: ");
    uart_send_uint16(batt_mv);
    uart_send_string(" mV (");
    uart_send_uint16(batt_pct);
    uart_send_string("%)\r\n");
#endif
#if LCD_ENABLED
    if (lcd_present)
        uart_send_string("Display: detected\r\n");
    else
        uart_send_string("Display: not found\r\n");
#endif
#if TREATMENT_MODE == TREATMENT_MODE_CONTINUOUS
    uart_send_string("Mode: CONTINUOUS (dry-cup auto-stop)\r\n");
#else
    uart_send_string("Mode: TIMED (");
    uart_send_uint16(TREATMENT_TIME_SEC);
    uart_send_string(" sec)\r\n");
#endif
#if BOOST_MODE == BOOST_MODE_MODULE
    uart_send_string("Boost: external module\r\n");
#else
    uart_send_string("Boost: discrete (DAC-controlled)\r\n");
#endif
    uart_send_string("Ready. Press button to start.\r\n");

    /* ---- Main loop ---- */
    while (1) {

#if BATTERY_ENABLED
        /* Sample the LiPo cell on a slow cadence */
        battery_sample_step();

        /* Auto-stop if the cell is critically low during a running
         * treatment. This protects the LiPo from over-discharge in
         * addition to the TP4056/DW01A hardware cutoff at ~2.5V. */
        if (batt_critical_latched &&
            (state == STATE_RUNNING || state == STATE_SWEEP
#if BOOST_MODE == BOOST_MODE_DISCRETE
             || state == STATE_BOOST_RAMP
#endif
            )) {
            uart_send_string("BAT: critical, auto-stopping\r\n");
            stop_nebulization();
#if LCD_ENABLED
            if (lcd_present) {
                lcd_show_message("LOW BATTERY     ",
                                 "Please recharge ");
                lcd_refresh_cooldown_ms = 2000;
            }
#endif
        }
#endif

#if LCD_ENABLED
        lcd_refresh_step();
#endif

        /* Check for button press in any state */
        if (button_debounced()) {
            if (state == STATE_RUNNING || state == STATE_SWEEP
#if BOOST_MODE == BOOST_MODE_DISCRETE
                || state == STATE_BOOST_RAMP
#endif
            ) {
                /* Button during operation = stop */
                stop_nebulization();
                delay_ms(500);  /* Debounce delay after stop */
                continue;
            } else if (state == STATE_IDLE || state == STATE_ERROR) {
#if BATTERY_ENABLED
                /* Refuse to start if battery is critically low */
                if (batt_critical_latched || batt_mv < BATTERY_CRIT_MV) {
                    uart_send_string("BAT: too low, start inhibited\r\n");
#if LCD_ENABLED
                    if (lcd_present) {
                        lcd_show_message("LOW BATTERY     ",
                                         "Charge via USB-C");
                        lcd_refresh_cooldown_ms = 2000;
                    }
#endif
                    delay_ms(500);
                    continue;
                }
#endif
                /* Button in idle/error = start */
#if BOOST_MODE == BOOST_MODE_DISCRETE
                uart_send_string("START: beginning boost ramp\r\n");
                current_dac = BOOST_STARTUP_DAC;
                dac_set_value(current_dac);
                state = STATE_BOOST_RAMP;
#else
                /* No ramp needed — boost module is already at target voltage */
                uart_send_string("START: beginning sweep\r\n");
#if BOOST_MODE == BOOST_MODE_MODULE
                error_boost_low = 0;
#endif
                state = STATE_SWEEP;
#endif
            }
        }

        /* ---- State machine ---- */
        switch (state) {

        case STATE_IDLE:
            /* Just wait for button press */
            break;

#if BOOST_MODE == BOOST_MODE_DISCRETE
        case STATE_BOOST_RAMP:
            /* Gradually increase boost voltage to target */
            if (boost_ramp_step()) {
                /* Ramp complete — start frequency sweep */
                uart_send_string("RAMP: boost at target, starting sweep\r\n");
                state = STATE_SWEEP;
            } else {
                delay_ms(BOOST_RAMP_DELAY_MS);
            }
            break;
#endif

        case STATE_SWEEP:
            /* Scan for PZT resonant frequency (tries cache first if available) */
            start_sweep();

            if (resonance.found) {
                /* Resonance found — start nebulizing */
                uart_send_string("RUN: nebulizing\r\n");

#if BOOST_MODE == BOOST_MODE_DISCRETE
                /* Enable the CWG to drive the boost MOSFET */
                CWG1CON0bits.G1EN = 1;
#endif

                /* Save this frequency for next startup */
#if FREQ_CACHE_ENABLED
                if (resonance.peak_inc != cached_freq) {
                    sweep_save_cached_freq(resonance.peak_inc);
                    cached_freq = resonance.peak_inc;
                }
#endif

                /* Start treatment timer */
                treatment_ticks = 0;
                recheck_ticks   = 0;
                dry_cup_ticks   = 0;
                timer1_start();

                state = STATE_RUNNING;
            } else {
                /* No resonance found — check boost voltage for a clearer error */
                dac_set_value(0);
#if BOOST_MODE == BOOST_MODE_DISCRETE
                current_dac = 0;
#endif

#if BOOST_MODE == BOOST_MODE_MODULE && BOOST_VFDBK_MIN_ADC > 0
                {
                    uint16_t vfdbk = adc_read(ADC_CH_BOOST_VFDBK);
                    uart_send_string("BOOST VFDBK ADC=");
                    uart_send_uint16(vfdbk);
                    uart_send_string("\r\n");
                    if (vfdbk < BOOST_VFDBK_MIN_ADC) {
                        error_boost_low = 1;
                        uart_send_string("ERROR: Vboost too low — check module\r\n");
                    } else {
                        error_boost_low = 0;
                        uart_send_string("ERROR: no cup detected\r\n");
                    }
                }
#else
                uart_send_string("ERROR: no cup detected\r\n");
#endif

                state = STATE_ERROR;
                error_blink_count = 0;
            }
            break;

        case STATE_RUNNING:
            /* Count Timer1 overflows for treatment/recheck timing */
            if (timer1_overflow()) {
                timer1_clear_overflow();
                treatment_ticks++;
                recheck_ticks++;

#if TREATMENT_MODE == TREATMENT_MODE_TIMED
                /* Check if treatment time is up */
                if (treatment_ticks >= treatment_max_ticks) {
                    uart_send_string("TIMER: treatment complete\r\n");
                    stop_nebulization();
                    break;
                }
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

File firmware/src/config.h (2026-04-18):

/*
 * config.h — Tunable parameters for the vibrating mesh nebulizer controller
 *
 * Adjust these values to match your specific nebulizer cup and power supply.
 * START CONSERVATIVE (low voltage, wide sweep) and dial in from there.
 *
 * Based on Microchip AN2265 reference design for PIC16F1713.
 */

#ifndef CONFIG_H
#define CONFIG_H

/* =========================================================================
 * FIRMWARE VERSION
 *
 * Single source of truth for the version string. Bump this on every
 * release and update CHANGELOG.md to match. Used by main.c for the
 * splash screen and UART banner, and by tests / bug reports for triage.
 * ========================================================================= */
#define FIRMWARE_VERSION_MAJOR  3
#define FIRMWARE_VERSION_MINOR  1
#define FIRMWARE_VERSION        "v3.1"

/* =========================================================================
 * CLOCK CONFIGURATION
 * The PIC16F1713 internal oscillator runs at 16 MHz (HFINTOSC).
 * All frequency calculations below assume Fosc = 16 MHz.
 * ========================================================================= */
#define _XTAL_FREQ          16000000UL  /* 16 MHz internal oscillator */

/* =========================================================================
 * FREQUENCY SWEEP PARAMETERS
 *
 * The controller sweeps across this range to find the PZT resonant frequency.
 * Aerogen Solo cups typically resonate around 128 kHz, but this varies
 * unit-to-unit and with liquid loading.
 *
 * If using a different brand of VMN cup, you may need to widen this range.
 * See README.md compatibility table.
 * ========================================================================= */
#define SWEEP_FREQ_MIN_HZ   90000UL     /* Lower sweep bound (Hz) */
#define SWEEP_FREQ_MAX_HZ   150000UL    /* Upper sweep bound (Hz) */
#define SWEEP_STEP_HZ       500UL       /* Step size during sweep (Hz) */

/*
 * NCO increment register calculation:
 *   NCO_INC = (freq_hz * 2^20) / Fosc
 *   NCO_INC = (freq_hz * 1048576) / 16000000
 *   NCO_INC = freq_hz * 65.536 / 1000
 *   Simplified: NCO_INC = (freq_hz * 65536UL) / 1000000UL  (close approx)
 *
 * At 90 kHz:  NCO_INC = 5898
 * At 128 kHz: NCO_INC = 8389
 * At 150 kHz: NCO_INC = 9830
 * Step of 500 Hz: NCO_STEP = ~33
 */
#define NCO_INC_MIN         ((uint16_t)((SWEEP_FREQ_MIN_HZ * 65536UL) / 1000000UL))
#define NCO_INC_MAX         ((uint16_t)((SWEEP_FREQ_MAX_HZ * 65536UL) / 1000000UL))
#define NCO_INC_STEP        ((uint16_t)((SWEEP_STEP_HZ * 65536UL) / 1000000UL))

/* Dwell time at each frequency step during sweep (milliseconds).
 * Longer dwell = more accurate peak detection but slower sweep. */
#define SWEEP_DWELL_MS      5

/* Number of ADC samples to average at each frequency step.
 * More samples = less noise but slower sweep. */
#define SWEEP_AVG_SAMPLES   4

/* =========================================================================
 * BOOST CONVERTER PARAMETERS
 *
 * DAC1 controls the boost output voltage via a feedback comparator.
 * The PIC16F1713 has a 5-bit DAC (0-31).
 *
 * WARNING: Start with a LOW value and increase gradually.
 * Too much voltage will damage or depolarize the PZT element.
 *
 * Approximate VBOOST vs DAC value (depends on your voltage divider):
 *   DAC  8  -> ~6V
 *   DAC 12  -> ~9V
 *   DAC 16  -> ~12V
 *   DAC 20  -> ~15V
 *   DAC 24  -> ~18V
 *
 * These are rough estimates. Measure VBOOST with a multimeter and adjust.
 * ========================================================================= */
#define BOOST_TARGET_DAC    16          /* Start at ~12V. Range: 0-31. */
#define BOOST_STARTUP_DAC   8           /* Soft-start value — ramps up from here */
#define BOOST_RAMP_DELAY_MS 50          /* Delay between DAC increments during ramp */
#define BOOST_MAX_DAC       24          /* Safety limit — never exceed this */

/* Boost hardware mode:
 *   DISCRETE — use the on-board boost converter (L1, Q2, D1, etc.).
 *              Full DAC-controlled feedback loop. Original AN2265 design.
 *   MODULE   — use a pre-built adjustable boost module (MT3608, XL6009, etc.).
 *              Set the module's output voltage to ~12V with its trim pot.
 *              Eliminates L1, Q2, D1, R9, R5, R8, C2, C9, and all boost
 *              firmware (DAC ramp, CWG drive). Much simpler to build.
 *              See docs/BUILD_GUIDE.md for details. */
#define BOOST_MODE_DISCRETE     0
#define BOOST_MODE_MODULE       1
#define BOOST_MODE              BOOST_MODE_MODULE   /* Turnkey build uses pre-built boost module */
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

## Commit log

2026-04-11 Add complete breadboard build guide, firmware, and documentation
    Provides everything needed to build a DIY vibrating mesh nebulizer controller
    on a breadboard for ~$73, based on the Microchip AN2265 reference design
    targeting the PIC16F1713 MCU.
    Includes:
    - Full breadboard build guide with stage-by-stage assembly instructions
    - Bill of materials (CSV) with DigiKey part numbers and TH substitutions
    - Pin-by-pin wiring reference with ASCII pinout diagrams
    - Complete PIC16F1713 firmware (XC8): NCO frequency sweep, DAC-controlled
    boost converter, ADC feedback sensing, state machine with treatment timer
    - Tunable config.h for sweep range, drive voltage, and timing parameters
    - FDA/regulatory d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
    [BOM.csv]
2026-04-11 Simplify controller design: continuous mode, dry-cup detection, boost module option
    Major improvements aimed at reducing cost, simplifying assembly, and supporting
    heavy daily nebulization schedules (100+ mL/day):
    Firmware:
    - Add continuous treatment mode (default) — runs until button press or dry cup,
    no more arbitrary timer cutting off long airway clearance sessions
    - Add dry-cup auto-stop — detects empty cup via sustained low current and shuts
    down safely, preventing mesh overheating during unattended operation
    - Add narrow re-sweep (~150ms) for fast resonance re-acquisition when frequency
    drifts during long sessions, instead of full 2.4-second sweep
    - Add frequency caching via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
    [BOM_SIMPLIFIED.csv]
2026-04-11 Add build quality guide, enclosure options, nursery durability, and mermaid diagrams
    Build quality:
    - Wire color guide for consistent, debuggable wiring
    - Common mistakes section (wrong PIC package, reversed diode, wrong cap
    value, grounding issues, breadboard contact degradation, etc.)
    - Test points and debugging table with expected values
    - UART debug emphasized as primary diagnostic tool
    Enclosure and physical protection:
    - Three tiers: breadboard case (simplest), perfboard (recommended for
    daily use), custom PCB (best quality)
    - Specific enclosure recommendations (Hammond 1591XXDSBK, clear container)
    - Mounting, cable glands, labeling guidance
    Nursery durability (6x/day use):
    - Moi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
2026-04-11 Add 3D-printable cup adapters, JLCPCB turnkey build, and enclosure designs
    Introduce a complete adapter system for connecting to various nebulizer cups
    via spring-loaded pogo pins, a turnkey BOM for JLCPCB pre-assembled PCBs
    that eliminates nearly all soldering, and a parametric 3D-printable enclosure
    with integrated adapter dock.
    New files:
    - hardware/adapters/ — Parametric OpenSCAD adapters for Aerogen Solo and
    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
    [BOM_TURNKEY.csv, aerogen_solo_adapter.scad, controller_enclosure.scad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]
2026-04-12 Consolidate to turnkey build, add battery compartment and connector plug
    - Remove full discrete and simplified build options, consolidate to single
    turnkey (JLCPCB-assembled) build path
    - Default config.h to BOOST_MODE_MODULE
    - Remove BOM.csv and BOM_SIMPLIFIED.csv, keep only BOM_TURNKEY.csv
    - Rewrite BUILD_GUIDE.md focused on turnkey assembly
    - Simplify DIAGRAMS.md: remove BOOST_RAMP state, discrete power path,
    unused ADC channels
    - Add battery compartment (3x AAA) to controller_enclosure.scad alongside
    PCB cavity, with retaining ribs and wire routing slot
    - Replace aerogen_solo_adapter.scad (cradle design) with
    aerogen_connector_plug.scad — a plug that mates with the cup's ~1/2"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
    [BOM.csv, BOM_SIMPLIFIED.csv, aerogen_connector_plug.scad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]
2026-04-12 Prep for public release: CI, changelog, gitignore, version fix
    - Update firmware version string from v2.0 to v3.0 to match project version
    - Add .gitignore for build artifacts, IDE files, and OS junk
    - Add CHANGELOG.md documenting v1.0 through v3.0 release history
    - Add GitHub Actions workflows:
    - firmware-check.yml: cppcheck static analysis on firmware/src
    - docs.yml: markdownlint for all Markdown documentation
    - openscad.yml: validate all .scad files render without errors
    - Add .markdownlint.json config (allow long lines, inline HTML)
    https://claude.ai/code/session_016JH6WWcjuKA2QpE53eeTTe
    [main.c]
2026-04-12 Add LiPo battery monitoring and 1602 character LCD driver
    Firmware changes for the v3.1 quality-of-life upgrade:
    - config.h: Battery thresholds (full/nominal/low/critical mV),
    FVR-based ADC method for measuring VDD = Vbat with zero external
    components, LCD pin assignments (RC4 SDA, RC5 SCL), HD44780
    backpack bit map, NCO_INC_TO_HZ conversion macro.
    - peripherals.c/h: Enable FVR at 2.048V and add battery_read_mv()
    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
2026-04-12 Add LCD_IS_OLED option for HD44780-compatible character OLEDs
    A drop-in replacement for the cheap 1602 LCD is a character OLED
    module like the Winstar WEH001602 (WS0010), Newhaven NHD-0216AW
    (US2066) or Matrix Orbital MOP-AO162. These modules speak the
    standard HD44780 4-bit command set via the same PCF8574 I2C
    backpack, so the existing driver works with only a slightly
    extended init sequence: a longer power-on settle, an explicit
    display-off before the final display-on, and a small post-clear
    settle to avoid the cold-start garbled first frame some OLED
    controllers exhibit.
    Config is a single LCD_IS_OLED toggle. Default stays at 0 (LCD)
    so existing builds are unaffected. The backlight bit i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
    [config.h, lcd.c]
2026-04-12 Split enclosure into base + lid + config, add LiPo bay and LCD window
    The v3.0 enclosure was a single 415-line file that rendered both the
    base and lid together. With the v3.1 feature additions (LiPo pouch
    cell bay, TP4056 charging shelf, 16x2 display window, four LCD
    mounting standoffs) the file was about to double in size and the two
    parts want to be iterated on independently. Split into:
    - enclosure_config.scad — shared parameters and helper modules
    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
    [controller_enclosure.scad, controller_enclosure_lid.scad, enclosure_config.scad]
2026-04-12 Update docs for v3.1: LiPo, USB-C charging, and character display
    Refreshes WIRING.md with the new LiPo/TP4056 power diagram and LCD
    I2C pinout, updates the turnkey BOM with the new parts and cost
    estimates, rewrites the build guide assembly steps for the LiPo bay
    and lid-mounted display, and adds a v3.1 entry to the changelog.
    https://claude.ai/code/session_01DLF9RkNd5aPgCf1gZW4TPa
    [BOM_TURNKEY.csv]
2026-04-12 Nimbus rename + 5 correctness fixes from post-audit
    Naming
    - Device is now Nimbus Nebulizer Controller
    - LCD splash: "Nimbus Nebulizer / Controller v3.1"
    - UART banner updated; log says "Display:" (not "LCD:")
    - README title, BUILD_GUIDE title and splash example updated
    Display
    - LCD_IS_OLED now defaults to 1 (character OLED)
    OLEDs run 3.0-5.5 V — no contrast issues over the LiPo range
    HD44780 LCD still supported via LCD_IS_OLED = 0
    Timer1 elapsed-time fix
    - Replaced TICKS_PER_SEC=8 (4.8% fast) with TIMER1_MS_PER_TICK=131
    - TICKS_TO_SEC now: ticks * 131 / 1000 (<0.1% error)
    - treatment_max_ticks now: sec * 1000 / 131
    - A 30-min TIMED session no longer ends 86 s early
    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
    [config.h, main.c]
2026-04-12 Update Aerogen Solo connector with caliper-verified measurements
    Replace estimated inch-fraction dimensions with caliper-measured values:
    - housing_width: 12.7mm → 7.25mm (wider slot axis, along pin row)
    - housing_depth: 12.7mm → 5.25mm (narrower slot axis)
    - housing_height: 6.0mm → 7.25mm (slot recess depth)
    - pin_spacing: 3.175mm → 3.25mm (center-to-center, verified)
    Remaining estimates (pin_diameter, pin_length, corner_r) flagged for
    follow-up measurement.
    https://claude.ai/code/session_018w4zuVh5qn4wQyYfsdc3GF
    [aerogen_connector_plug.scad]
2026-04-12 Update Aerogen Solo connector with caliper-verified pin measurements
    Set pin_diameter to 1.1mm, pin_length to 8.5mm, and housing_corner_r
    to 0 (sharp-edged slot) based on physical caliper measurements.
    Removes all remaining VERIFY annotations from the connector spec.
    https://claude.ai/code/session_0194x7sy8YtqCwMdsThx95PH
    [aerogen_connector_plug.scad]
2026-04-12 Redesign connector plug for stepped housing (10×8 outer, 7.25×5.25 inner)
    Full housing depth is 16.5mm with a two-section profile: 10mm×8mm outer
    entry section (9.25mm deep) stepping down to the 7.25mm×5.25mm inner pin
    slot (7.25mm deep). Replaces the single-tongue design with a three-section
    stepped body — flange, outer section, inner tongue — matching the housing
    geometry. Removes plug_wall/plug_base_thickness/plug_insertion_depth in
    favour of housing_outer_*/housing_inner_* parameters and plug_flange_*.
    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
    [aerogen_connector_plug.scad]
2026-04-13 Fix lid fit: center LCD on enclosure instead of PCB cavity
    The LCD window, mounting standoffs, and screw holes were all translated
    by pcb_offset_x (-19.7 mm), which biased a nearly-full-width LCD toward
    the PCB side of the enclosure. This pushed the 72 mm window past the
    left edge of the 96.4 mm lid (x = -55.7, outside the ±48.2 outer plate
    and ±45.7 inner lip), cutting a hole through both the outer wall and
    the sealing lip. The left LCD mounting standoff (x = -57.2) fell
    entirely outside the lid plate and rendered as a floating cylinder.
    Add lcd_window_offset_x (default 0) to enclosure_config.scad and use it
    for the window, standoffs, and mount holes. With the LCD centered on
    the enclosu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
    [controller_enclosure_lid.scad, enclosure_config.scad]
2026-04-13 Fix aerogen connector plug: buried chamfer overlap and solder-tail recess
    Three geometry issues corrected:
    1. Step chamfer was placed starting 1mm before the outer section body
    ended, so it was 100% inside the outer-section volume in union().
    The intended taper had zero effect, and OpenSCAD F5 preview showed
    coplanar Z-fighting on the shared faces.
    Fix: shorten outer-section height to housing_outer_h-1.0 so the
    chamfer occupies that freed 1mm (total outer zone unchanged at 9.25mm).
    2. Wider solder-cup recess (h=4.1, reaching z=4.0) did not reach the
    pogo socket solder tail, which sits at z=6.0 when the socket is
    correctly positioned with its receiving bore at z=22.5 (i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
    [aerogen_connector_plug.scad]
2026-04-13 Fix impossibly thin geometry: flange height, cable exit wall, strain relief
    Three interdependent geometry problems resolved:
    1. plug_flange_h 6→7mm (user measurement): with the previous 6mm flange
    the cable exit cylinder (d=cable_channel_h+1) top landed at z=6.5,
    0.5mm above the flange top face, punching an open notch through the
    top back edge — zero wall thickness.
    2. cable_channel_h reverted 4.0→3.5mm: the prior session raised this to
    align wire channels with the solder tail, but that made d=5.0 and the
    exit top z=6.5. With flange_h=7.0 and the original 3.5mm channel,
    d=4.5, exit top=z=6.0, giving a clean 1.0mm wall to the new flange
    top at z=7.0. The solder ta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
    [aerogen_connector_plug.scad]
2026-04-13 Fix strain relief slot z=0 impossible geometry on flange bottom edge
    The slot was translated to z=0, making its bottom face co-planar with
    the flange bottom — an impossible/non-manifold edge in the rendered mesh.
    Raise the slot bottom to z=0.5 (strain_relief_slot_z) and trim height
    from 1.2 to 0.9 so the slot top stays at z=1.4, clear of the cable exit
    void floor at z=1.5.
    https://claude.ai/code/session_01KpharfzpyNx3q3SrdphEjQ
    [aerogen_connector_plug.scad]
2026-04-18 Repo improvements: governance, tests, CI, OpenSCAD fixes
    Adds the project-governance and tooling pieces that were missing
    (CONTRIBUTING.md, SECURITY.md, issue/PR templates, pre-commit), wires
    up host-side firmware unit tests in CI, fills out the hardware/README,
    and fixes several real bugs in the OpenSCAD models.
    Governance & docs
    - CONTRIBUTING.md, SECURITY.md, hardware/README.md
    - .github/ISSUE_TEMPLATE/{bug,feature,cup_compatibility}.yml + config.yml
    - .github/pull_request_template.md with safety-review checklist
    Build & CI
    - firmware/Makefile that auto-discovers all sources under src/
    - firmware/tests/ (config-math, battery SOC, LCD formatting) wired into
    the existing firmware-check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
    [controller_enclosure.scad, controller_enclosure_lid.scad, universal_adapter.scad]
2026-04-18 docs: add shopping list and improvement-suggestions memo
    - docs/SHOPPING_LIST.md: per-supplier cart lists (JLCPCB/LCSC,
    Amazon/AliExpress, DigiKey/Mouser) with SKUs, pack sizes, and
    single-build + 5-build checklists.
    - docs/IMPROVEMENTS.md: external-review memo with prioritised
    repo-clarity fixes, design simplifications, cost-reduction
    options (SSD1306 swap, connector/screw standardisation),
    speed-to-build proposals (pre-rendered STL + pre-built hex
    release artifacts), and safety-robustness additions
    (absolute treatment-time cap, VBOOST overvoltage trip,
    resonance plausibility guard, power-on self-test).
    - README.md: link both new docs from Quick Start and the repo
    struct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
